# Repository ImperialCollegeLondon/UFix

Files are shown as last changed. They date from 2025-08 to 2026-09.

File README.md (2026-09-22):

# UFix: 3D Printed External Fixator
## Releases
UFix is made available on the following 3D model databases:
- [**UFix on Printables**](https://www.printables.com/model/1839361-ufix-emergency-external-fixator-surgical-bone-stab)

Please check [here for the latest design release on GitHub](https://github.com/ImperialCollegeLondon/UFix/releases), with version history and a list of changes.

## Overview
**UFix** is a novel 3D printed external fixator device developed at Imperial College London. This project is intended for **research purposes only** and is currently **not for clinical use.** The UFix is under continuous development and refinement.

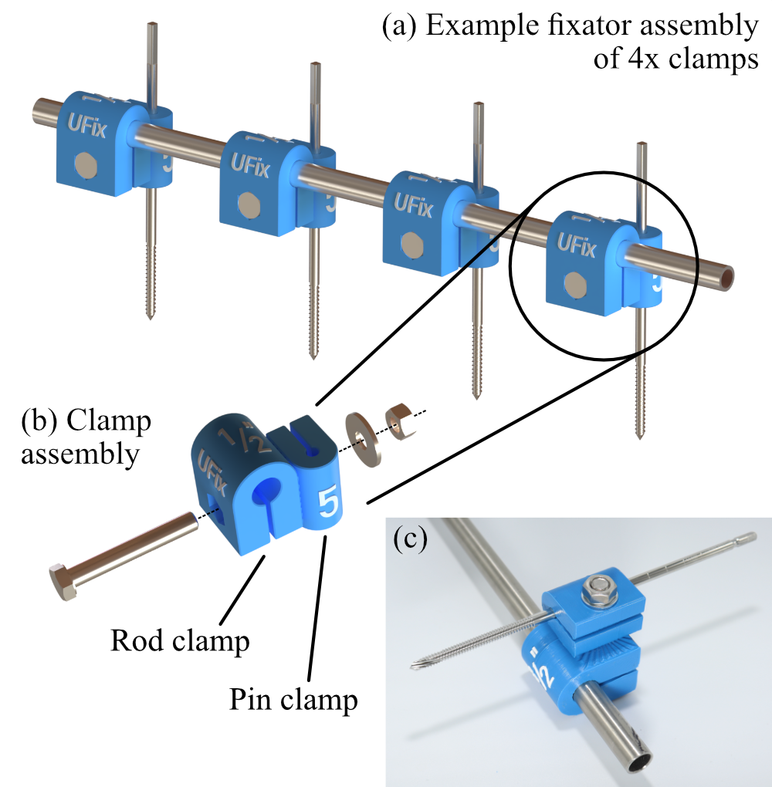
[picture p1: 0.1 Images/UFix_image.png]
UFix Model Image


## Status and Disclaimer
- **Development Stage:** Prototype phase; subject to further design and testing.
- **Clinical Use:** Strictly prohibited. The device is for research, academic, and educational purposes only.
- **Licensing:** This work is licensed under a **Creative Commons Attribution-NonCommercial-NoDerivatives 4.0 International License** ([**CC BY-NC-ND 4.0**](https://creativecommons.org/licenses/by-nc-nd/4.0/)). It is not permitted to build derivative models based on UFix or its features and make them publicly available.

## Features
- **CAD Design:** Developed in SolidWorks.
- **Testing:** Subjected to preliminary Finite Element Analysis (FEA) and mechanical testing at Imperial College London.
- **Adaptability:** Initially designed for lower limb applications but can be adapted for upper limb use via parametric modelling of rod and pin sizes.
- **Assembly:** Simple and inspired by commercial external fixators, modelled after the metal [Imperial External Fixator](https://imperial.ac.uk/external-fixator).
- **Sizes:** Currently only imperial 0.5" rod supported, with bone pin 5mm.

## 3D Printing Information
- **Printer:** Prusa MK4
- **Printer Settings:** 0.2mm Speed preset, 100% infill, no supports
- **Material Selection:** Recommended material is **PLA**.  
Choice of 3D printing material depends on local material availability and printer compatibility, however note this may affect performance/strength and has not been tested!
Materials and printer models may change as testing progresses.

## Repository Contents
- **Print Files:** 3MF file ready for printing.
- **SolidWorks Files:** Source CAD files for UFix components.
- **Assembly Instructions:** Step-by-step guide for assembling the fixator.
- **Bill of Materials:** List of components needed to assemble the fixator.

## Usage Guidelines
- For research and educational usage only.
- Not certified or tested for human or animal clinical procedures.
- Do not attempt to modify, distribute, or publish derivative works based on UFix designs.

## Contact & Acknowledgement
Developed by the research team in the Department of Bioengineering at Imperial College London.

Many thanks to all the researchers who have been involved in this project:  
[Dr Mehdi Saeidi](https://profiles.imperial.ac.uk/m.saeidi), [Dr Angus Clark](https://profiles.imperial.ac.uk/a.clark17), [Prof Anthony Bull](https://profiles.imperial.ac.uk/a.bull), Jenny Shang, Hannah Tollemache, and Kyung-Hoon Moon.

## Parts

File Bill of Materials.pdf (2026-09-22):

Assembly Name | UFix Fixator
Assembly Revision | V37
Date of Approval | 22/09/2026
Total Pieces | 25
Total Cost | £ 63.74

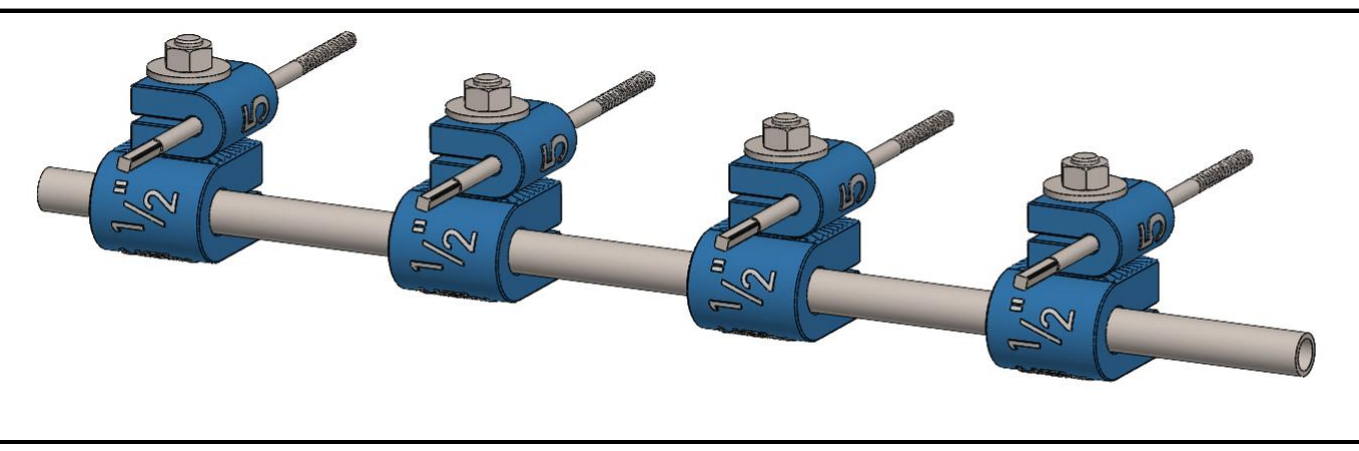
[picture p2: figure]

ITEM | MATERIAL | PART NUMBER | PART NAME | PART DESCRIPTION | SOURCE | UNIT COST | QTY. | TOTAL COST
1 | PLA | UFix_V37 | UFix Clamp | Combined 3D Printed Clamp | | £ 1.66 | 4 | £ 6.64
2 | SS | | Schanz Pin | Surgical bone pin | | £ 10.00 | 4 | £ 40.00
3 | SS 316 | | Solid Rod | 1/2 inch diameter, 30cm long rod | | £ 12.42 | 1 | £ 12.42
4 | SS 316 | SEBF-M8-55-A4-70 | Hexagon Head Bolt | ISO 4017, M8, 55mm length | Buy M8 x 55mm (https://www.accu.co.uk/full-thread-hexagon-bolts/630507-SEBF-M8-55-A4-70) Full Thread Hexagon Bolts (ISO 4017) High Tensile Steel (A4-70) - Accu £ | 0.89 | 4 | £ 3.56
5 | SS 316 | HPN-M8-V1-A4 | Hexagon Nut | ISO 4032, M8 | Buy M8 Hexagon (https://www.accu.co.uk/hexagon-nuts/406395-HPN-M8-V1-A4) Nuts (ISO 4032) - Marine Stainless Steel (A4) - Accu £ | 0.16 | 4 | £ 0.64
6 | SS 316 | HYW-M8-20-A2 | Washer | 8.4mm ID, 16mm OD, 1.6mm thickness | Buy M8 x 16mm (https://www.accu.co.uk/metric-flat-washers/391802-HAFZ-M8-A2) AFNOR Z-Type Flat Washers (NF E 25-514) - Stainless Steel (A2) - Accu £ | 0.06 | 8 | £ 0.48
| | | | | | TOTAL | 25 £ 63.74

* Costs are calculated based on a purchase quantity of 1000
* Costs therefore may be lower with higher quantities
* Printed costs are based on pure material costs, not including maintenance or upkeep
* Material costs are estimated based on generic pre-manufactured reels, not virgin pellets
UFix Fixator | Bill of Materials

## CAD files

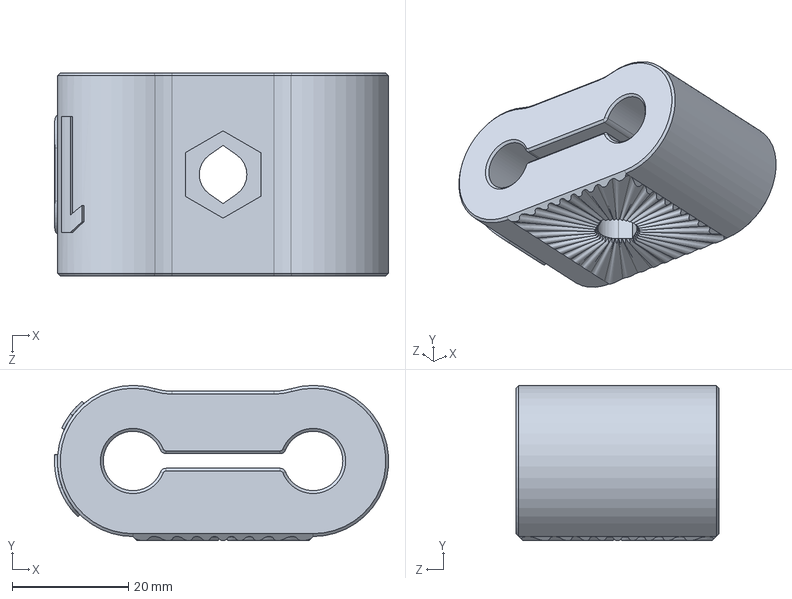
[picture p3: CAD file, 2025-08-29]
0.2 CAD/RODCLAMP_DOUBLE.SLDPRT
57.5 x 26.7 x 35.0 mm

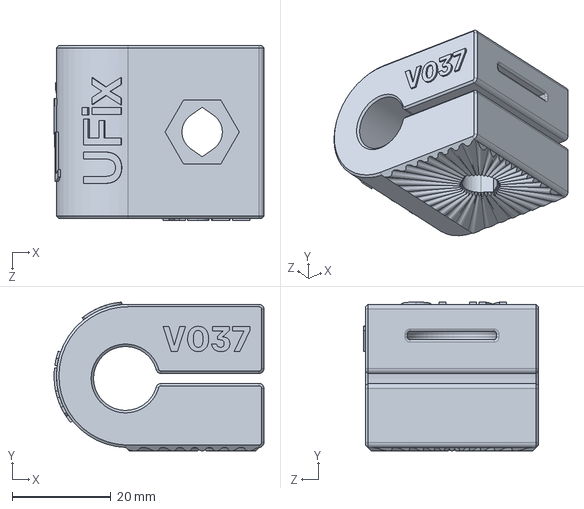
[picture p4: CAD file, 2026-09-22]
0.2 Design/CAD Files/SOLIDWORKS/RODCLAMP.SLDPRT
42.5 x 30.1 x 35.4 mm

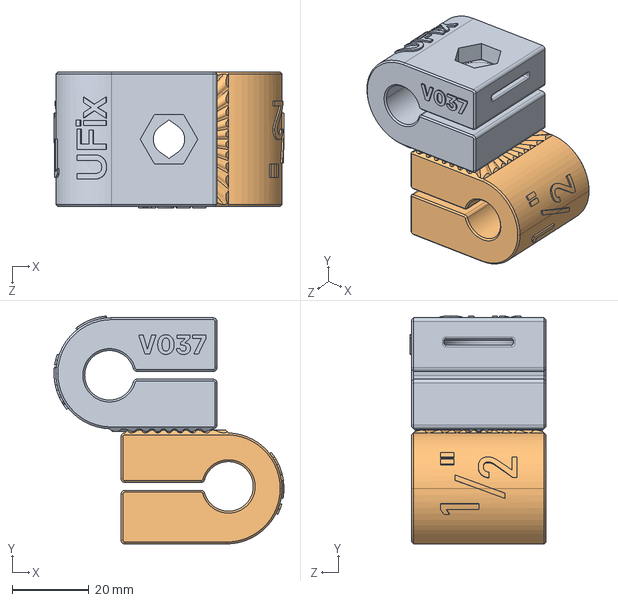
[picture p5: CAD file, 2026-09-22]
0.2 Design/CAD Files/STEP/UFIX_FIXATOR_CLAMP_DUAL.STEP
59.9 x 59.4 x 35.4 mm
RODCLAMP_.5"
RODCLAMP_DUAL_.5"

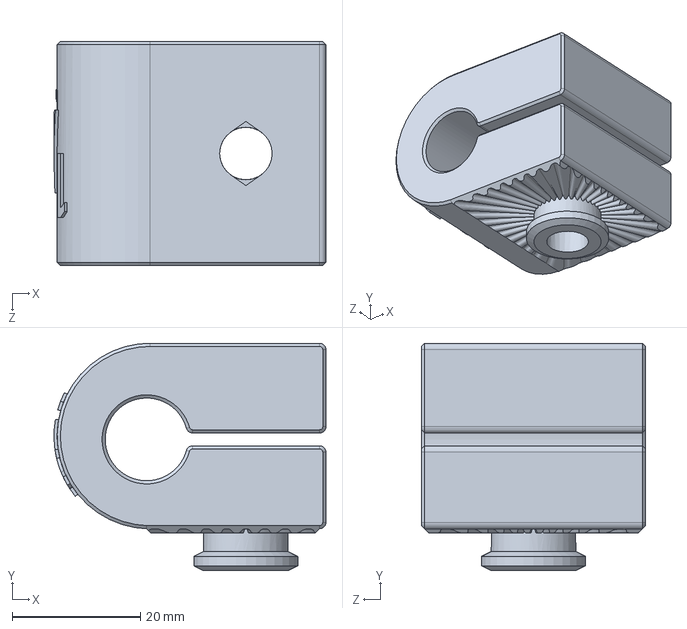
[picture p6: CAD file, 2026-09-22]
0.2 Design/CAD Files/SOLIDWORKS/RODCLAMP_DUAL.SLDPRT
42.5 x 35.5 x 35.0 mm

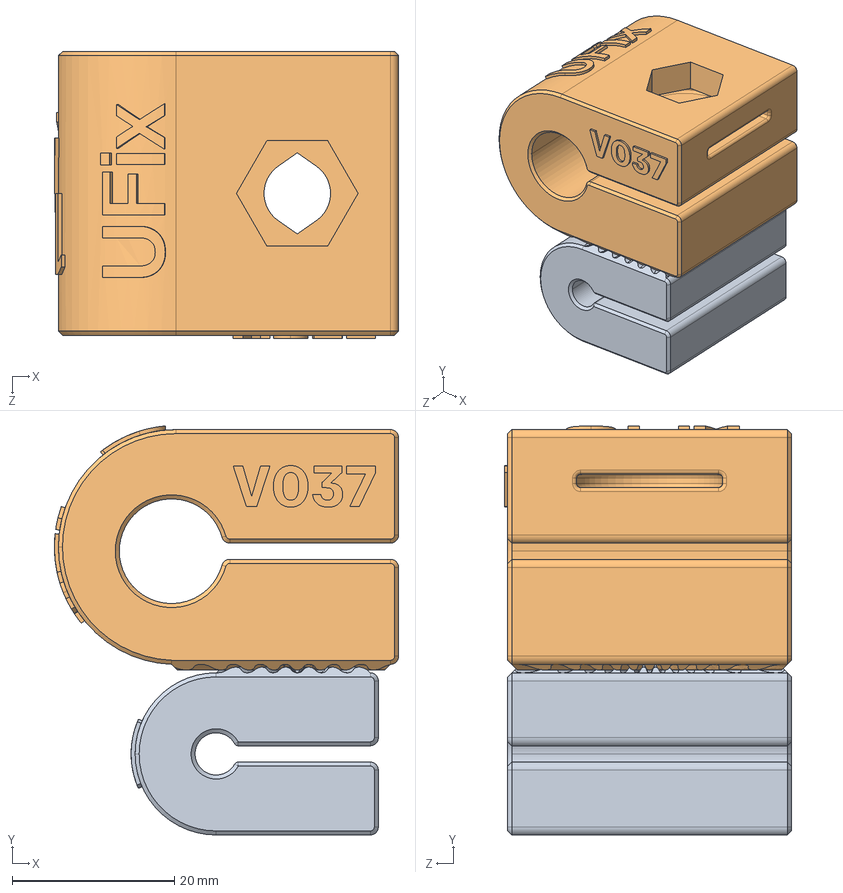
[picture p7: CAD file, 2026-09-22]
0.2 Design/CAD Files/STEP/UFIX_FIXATOR_CLAMP.STEP
42.5 x 50.4 x 35.4 mm
PINCLAMP_5
RODCLAMP_.5"

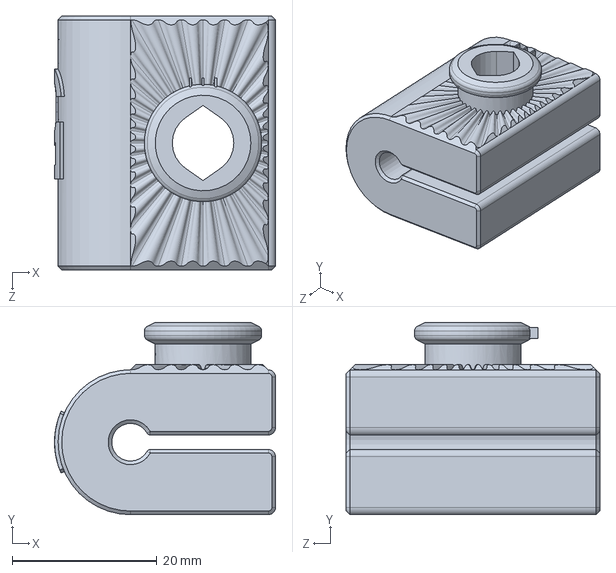
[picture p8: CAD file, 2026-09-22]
0.2 Design/CAD Files/SOLIDWORKS/PINCLAMP.SLDPRT
30.5 x 26.6 x 35.0 mm

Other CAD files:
0.2 Design/Print Files/UFIX_FIXATOR_CLAMP_DUAL_V37.3MF
0.2 Design/Print Files/UFIX_FIXATOR_CLAMP_5MM_V37.3MF
0.2 Design/CAD Files/SOLIDWORKS/UFIX_FIXATOR_CLAMP.SLDASM
0.2 Design/CAD Files/SOLIDWORKS/UFIX_FIXATOR_CLAMP_DUAL.SLDASM

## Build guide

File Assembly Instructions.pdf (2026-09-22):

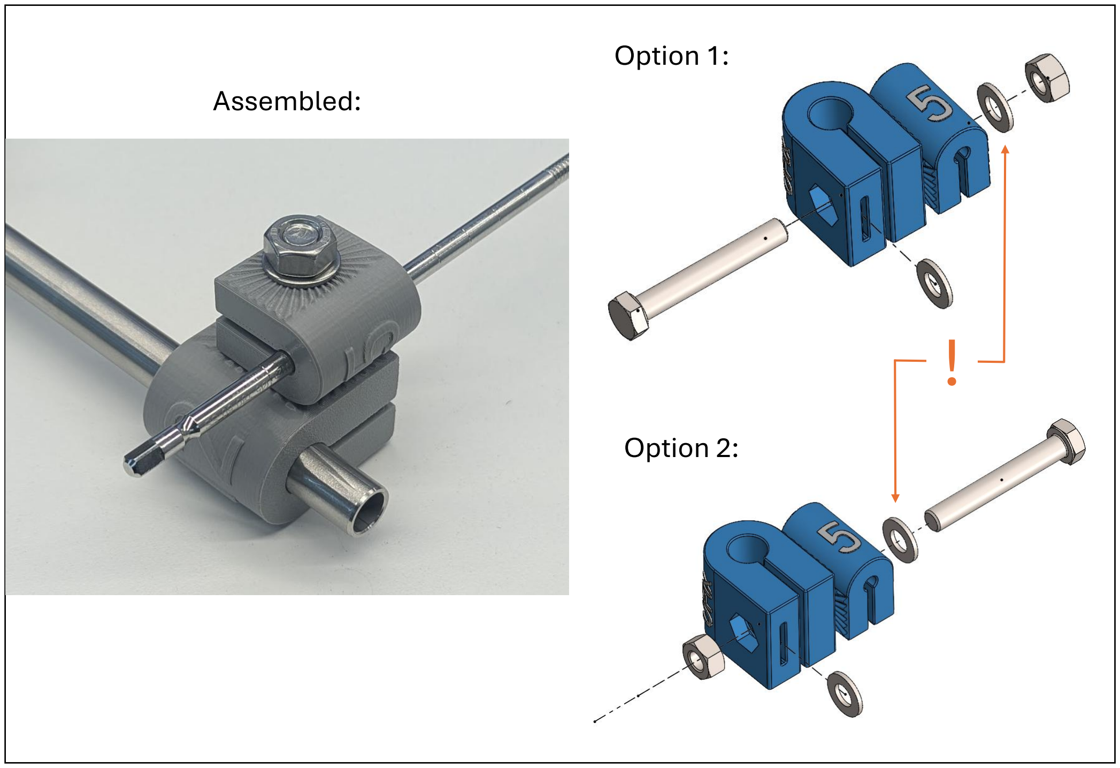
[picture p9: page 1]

!

Option 1:

Option 2:

Assembled:

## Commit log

2025-08-29 Files transferred from Sharepoint
    [Bill of Materials.xlsx, IFIX_3D_V2_PINCLAMP_5MM.STL, IFIX_3D_V2_RODCLAMP_10MM.STL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]
2025-08-29 Added test reports and reformatted test folder structure
    [PINCLAMP_2.5MM.3MF, PINCLAMP_2MM.3MF, PINCLAMP_3.5MM.3MF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]
2025-08-29 Updated BOM
    [Bill of Materials.xlsx]
2025-08-29 Added simulation files
    [SS 8MM Rod.SLDPRT]
2025-08-29 Updated folder structure
    [PINCLAMP_85.3MF, PINCLAMP_9.3MF]
2025-09-01 Updated CAD
    Added 4x clamp assembly files.
    Added setup image to readme.
    [PINCLAMP.SLDPRT, RODCLAMP.SLDPRT, SS 8MM Rod.SLDPRT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]
2025-09-01 Update README.md
    Added link to releases.
    Added more information to printing
2025-09-01 Reorganised folder structure.
    [4X Clamp Setup.SLDASM, Bill of Materials.xlsx, IFIX_3D_V2_PINCLAMP_5MM.STL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]
2025-09-02 Added documents
    Updated bill of materials and instructions for use.
    Added PDFs of above documents along with source files.
    [Bill of Materials.xlsx]
2025-09-02 Updated CAD assembly
    Updated CAD assembly for images of configurations.
    [1X Clamp Setup.SLDASM, 4X Clamp Setup.SLDASM, SS Rod 12.7MM 80MM.SLDPRT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]
2025-09-11 Readme Updated
    - Updated recommended material to PLA due to issues with PETG/ABS
    - Updated images in readme to new model
    - Added second image to readme showing alternative angle
    - Removed old image in readme
2025-09-11 Updated Assembly
    Updated model to half inch version.
    Updated clamp models to latest version.
    Updated colours.
    [4X Clamp Setup.SLDASM, SS Rod 12.7MM 400MM.SLDPRT]
2025-09-11 Moved old files to archive
    [RODCLAMP.SLDPRT, RODCLAMP_Logo.SLDPRT]
2025-09-11 Model update
    Updated model to include logo, and adjusted tolerances.
    [PINCLAMP.SLDPRT, RODCLAMP.SLDPRT]
2025-09-11 Added mechanical test (T006) and material test (T005)
    [PINCLAMP.3MF, PINCLAMP.SLDPRT, RODCLAMP.3MF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]
2025-09-12 CAD Files update and v3 release
    - Updated configurations for all sizes
    - Added image to readme showing sizes
    - Organised simulation/render files
    - Updated assemblies to reference new locations
    - Added new release of project (v3.0)
    [1X Clamp Setup.SLDASM, 4X Clamp Setup.SLDASM, IFIX_3D_V3_PINCLAMP_5MM.STL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]
2025-09-15 Added imaged of the printed Ex Fix
2025-09-15 New Release
    [IFIX_3D_V3_PINCLAMP_5MM.STL, IFIX_3D_V3_PRUSA_PROJECT_FILE.3mf, IFIX_3D_V3_RODCLAMP_0.5INCH.STL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]
2025-09-15 deleted release
    [IFIX_3D_V3_PINCLAMP_5MM.STL, IFIX_3D_V3_PRUSA_PROJECT_FILE.3mf, IFIX_3D_V3_RODCLAMP_0.5INCH.STL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]
2025-09-18 New materials - Release V4
    V4 Released, with specific versions for different materials. CAD files updated to accommodate different materials. Currently supported materials are PLA, PETG, and ABS.
    [IFIX_3D_V4_PINCLAMP_ABS_5MM.STL, IFIX_3D_V4_PINCLAMP_PLA_PETG_5MM.STL, IFIX_3D_V4_RODCLAMP_ABS_0.5INCH.STL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]
2026-08-22 Release V35
    - Renamed to UFix
    - Files updated to match
    [1X Clamp Setup.SLDASM, 4X Clamp Setup.SLDASM, Bill of Materials.xlsx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]
2026-09-22 V037 Updates
    Design:
    - Updated to V037
    -- Added washer slot
    -- Updated connection between clamps to print without support
    - Added alternative design for rod-rod clamping
    - Added STEP files as alternative to SolidWorks
    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
    [PINCLAMP.SLDPRT, RODCLAMP.SLDPRT, RODCLAMP_DUAL.SLDPRT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]
